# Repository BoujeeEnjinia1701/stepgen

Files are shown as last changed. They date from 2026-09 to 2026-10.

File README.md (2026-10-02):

# StepGen

     

**Area:** Mobility and Logistics · **TRL:** 3 of 9 (proof of concept on paper) · **Value-engineering target:** $650 USD on the salvage reference build (estimated cost of the constructable design $610), SwapCell pack excluded · **Difficulty:** 3 of 5

Walking-treadmill vehicle: the rider stands upright and walks at a normal pace on a short free-running belt between the wheels, a belt-speed sensor sets the assist of a 250 W hub motor, and the vehicle moves at e-bike speed (up to 25 km/h) on a shared SwapCell pack. Walking is the control input; the motor does the work.

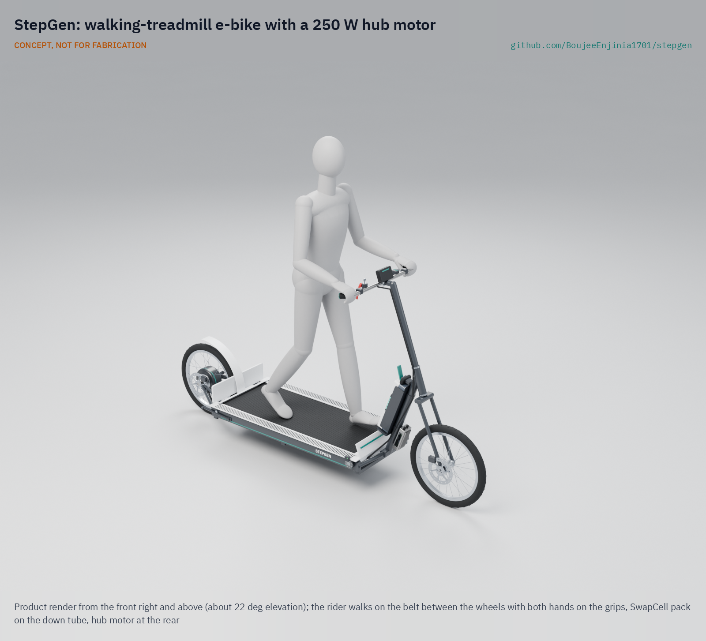
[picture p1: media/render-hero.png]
StepGen: walking-treadmill e-bike with a 250 W hub motor, product render


[Exploded render](media/render-exploded.png) · [Detail render](media/render-detail.png) · [Interactive 3D model](media/viewer.html) · [General arrangement (PDF)](cad/drawings/SGN-DWG-001.pdf) · [Concept blueprint (PDF)](media/concept-blueprint.pdf) · [Sizing note](docs/04-calcs/01-sizing.md) · [Prototype build plan](docs/05-build-plan.md) · [Design decisions](docs/06-design-decisions.md) · [Review note](docs/REVIEW.md)

## Concept rationale

Walking is the one way of moving that almost everyone already knows, so StepGen uses it as the control input instead of asking new riders to learn to pedal and balance on a saddle. The rider walks at an ordinary pace on a free-running belt; a sensor reads that pace and a 250 W hub motor does the propulsion, because a person walking puts only about 30 to 41 W into the belt, far less than the 136 W the vehicle needs at 20 km/h ([SGN-CAL-001](docs/04-calcs/01-sizing.md)). Walking sets the speed, gives light exercise and stops the motor as soon as the rider stops.

Commercial walking bikes exist but cost from about €3,000 and weigh about 55 kg ([Lopifit, "What is a Lopifit?"](https://www.lopifit.com/what-is-a-lopifit/)). StepGen is open hardware so that a local welder or bike mechanic can build it from a salvaged walking-pad treadmill, a donor 20 in bike and common e-bike parts for about $610, share one SwapCell pack with other portfolio vehicles, and adapt the design to the riders they serve.

## Burning platform

The WHO reports that 31 % of adults worldwide did not meet the recommended levels of physical activity in 2022, a share that has risen since 2010 ([WHO, physical activity fact sheet](https://www.who.int/news-room/fact-sheets/detail/physical-activity)). At the same time, populations are ageing: by 2030 one in six people in the world will be aged 60 or over, 1.4 billion people, and by 2050 two-thirds of them will live in low- and middle-income countries ([WHO, ageing and health fact sheet](https://www.who.int/news-room/fact-sheets/detail/ageing-and-health)).

Many of these people make short daily trips that are too long to walk and too costly by car, and e-bikes serve them only if they can already cycle. A vehicle driven by ordinary walking could give non-cyclists and older adults the reach of an e-bike together with daily activity, but only if it is cheap and simple enough to be built and repaired locally.

## Where it could be used

### By industry

| Industry | Use |
| --- | --- |
| Urban mobility and bike share | A pedal-free option in shared fleets for riders who do not cycle |
| Healthy ageing and community services | Errands and clinic visits for older adults who can walk but are nervous on a saddle |
| Workplace and campus mobility | Moving staff across large sites, factories, hospitals and universities at walking effort |
| Tourism and leisure | Rentals on promenades and park paths, where riding a walking bike is itself the attraction |
| Last-mile commuting | The trip between home and a train or bus station for commuters who want light exercise |
| Local fabrication and repair | A product that bike mechanics and welders can build and service from salvaged parts |

### By country or region

| Country or region | Why it matters there |
| --- | --- |
| Netherlands | 27 % of all journeys are made by bicycle and more than half of all car trips are shorter than 7.5 km ([Government of the Netherlands, bicycle policy](https://www.government.nl/topics/bicycles/bicycle-policy-in-the-netherlands)); the Lopifit walking bike was developed here ([Lopifit](https://www.lopifit.com/what-is-a-lopifit/)), so dense cycle infrastructure and a working reference vehicle already exist |
| Japan | 29.1 % of the population was aged 65 or over on 1 October 2023 ([Cabinet Office, Annual Report on the Ageing Society 2024](https://www8.cao.go.jp/kourei/english/annualreport/2024/pdf/2024.pdf)); an upright, walking-paced vehicle suits older adults on short local trips |
| United States | Federal e-bike law assumes operable pedals ([15 USC 2085](https://uscode.house.gov/view.xhtml?req=granuleid%3AUSC-prelim-title15-section2085&num=0&edition=prelim)), so a walking vehicle is a test case for how rules treat pedal-free, low-power assist |
| India | The world's second-largest market for electric two-wheelers, with 2023 sales up 40 % on 2022, and after subsidies an electric two-wheeler cost more than 15 % less than its petrol equivalent ([IEA, Global EV Outlook 2024](https://www.iea.org/reports/global-ev-outlook-2024/trends-in-other-light-duty-electric-vehicles)); buyers already choose light electric vehicles on price, so a low-cost build matters |
| Kenya | One of the countries where UNEP supports electric two- and three-wheeler projects, in a region where motorcycle numbers in many African countries are growing at some of the highest rates in the world ([UNEP, electric two and three wheelers](https://www.unep.org/topics/transport/electric-mobility/electric-two-and-three-wheelers)); a locally built vehicle on a shared SwapCell pack fits that shift, though demand and rules need a desk study |
| Latin America | Two- and three-wheelers play a critical role in daily passenger and commercial transport in Latin America and Africa ([IEA, Global EV Outlook 2024](https://www.iea.org/reports/global-ev-outlook-2024/trends-in-other-light-duty-electric-vehicles)); a light vehicle that local workshops can build and repair could serve the same trips |

## What sparked the idea

The starting point was the electric walking bike that Amish has seen in the Netherlands, of the Lopifit type: the rider walks upright on a treadmill belt between the wheels, and the bike moves forward instead of being pedalled. The Lopifit is a Dutch invention by Bruin Bergmeester, who drove to work, found it hard to keep a healthy weight and decided that should change; the company is based in Utrecht ([Lopifit, "What is a Lopifit?"](https://www.lopifit.com/what-is-a-lopifit/); [Lopifit, "Our story"](https://www.lopifit.com/our-story/)). It shows that a walking vehicle works and can be sold, but its price and mass put it out of reach of many of the people who would gain most from it. StepGen asks whether the same idea can be made light, open and garage-buildable on a shared battery.

## Problem

Many people who would gain from an e-bike never ride one because cycling needs riding skill, balance on pedals and a seated posture that does not suit everyone, while walking is natural and needs none of these. Short trips of 2 to 15 km stay too long to walk and too costly by car. Design with, not for: requirements must come from co-design sessions and field trials with the intended users through a local partner.

## Concept

Walking-treadmill vehicle: the rider stands upright and walks at a normal pace on a short free-running belt between the wheels, a belt-speed sensor sets the assist of a 250 W hub motor, and the vehicle moves at e-bike speed (up to 25 km/h) on a shared SwapCell pack. Walking is the control input; the motor does the work.

Full design precis: [docs/02-concept.md](docs/02-concept.md)

## Key components

- Long-wheelbase welded steel frame (2.38 m long with the fender, 1.86 m wheelbase, 60 x 30 x 2 mm deck rails) with two 20 in wheels
- Free-running treadmill belt on a roller bed, with a one-way bearing in the rear roller so the belt runs rearward only
- Belt-speed sensor that sets the motor assist
- 250 W geared rear hub motor and 48 V controller, assist cut at 25 km/h, 15 km/h beginner mode
- Shared 48 V SwapCell pack (interface v0.3) in a down-tube cradle to latch class V1, woken by a 10 kΩ INTERLOCK coding resistor (pack not in the parts cost)
- Two disc brakes with motor cut-off levers, a lanyard stop switch and a key switch in the SwapCell INTERLOCK loop
- Guards over the belt rollers and the rear tire

TRL 3 sizing ([SGN-CAL-001](docs/04-calcs/01-sizing.md)): about 9.1 Wh/km at 20 km/h, about 45 km per SwapCell pack on the flat, 35.1 kg without the pack, and an estimated $610 in parts excluding the pack on the salvage reference build, $40 under the $650 value-engineering target ($750 with all new parts; see [SGN-DDR-002](docs/decisions/0002-recommendations-accepted.md), [SGN-DDR-003](docs/decisions/0003-design-for-construction.md) and the [review note](docs/REVIEW.md)). The parametric model is `cad/src/model.py`, with STEP files in `cad/step/`.

The priced bill of materials is in [bom/bom.csv](bom/bom.csv).

## Building the prototype

The [prototype build plan](docs/05-build-plan.md) (SGN-BLD-001) shows how to build the first proof-of-concept StepGen, component by component, with a making sketch for every made part, close-ups of the joints and a picture for every assembly step. The frame is welded from stock steel tube and plate; the belt and rollers come from a used walking-pad treadmill and the wheels, brakes and motor are bought. Making the concept buildable changed some parts (rear stays, nose beam, head tube, cradle, guards and fixings) without changing what the vehicle does; the changes are in [SGN-DDR-003](docs/decisions/0003-design-for-construction.md), and decisions still open are in the [design decisions register](docs/06-design-decisions.md). It is a plan: building and testing to it is TRL 4 work.

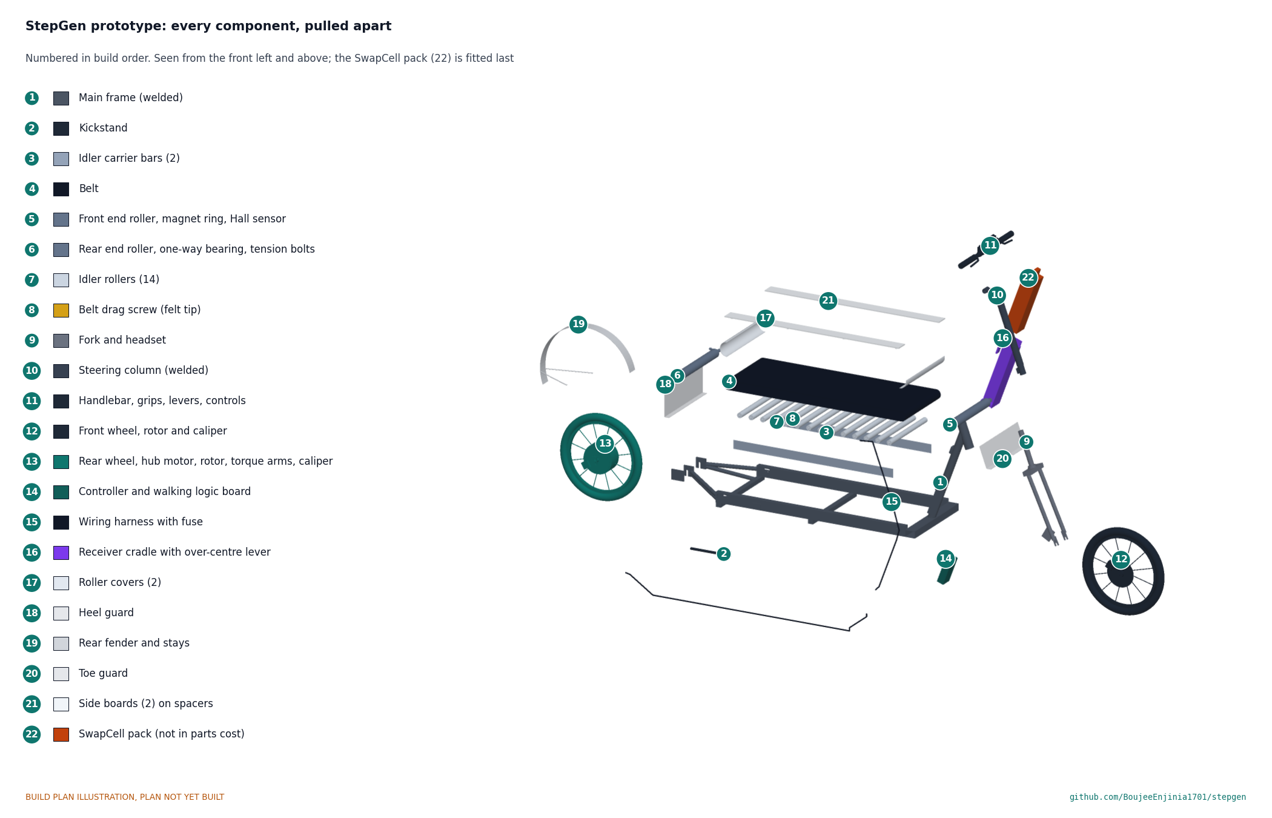
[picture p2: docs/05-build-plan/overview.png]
StepGen prototype: every component, pulled apart and numbered in build order


## Safety

> **Safety:** A rider stands on a moving belt on a moving vehicle. The motor must run only while the rider walks and stop when the belt stops, a brake is pulled or the lanyard comes out. Guard the belt rollers and the rear tire, keep the deck low with open sides, limit speed to 25 km/h, and wear a helmet. The SwapCell pack is a 468 Wh lithium-ion battery held by a class V1 latch; every circuit stays under 60 V DC. This is a paper design at TRL 3; nothing here clears it for building or riding.

## Repository layout

| Folder | Contents |
| --- | --- |
| `docs/` | Problem, concept, requirements, calculations, prototype build plan and design decisions |
| `cad/src/` | build123d Python source, the source of truth for all geometry |
| `cad/step/`, `cad/stl/` | Exported models for FreeCAD, other CAD tools and printing |
| `cad/drawings/` | 2D sketches and dimensioned drawings |
| `bom/` | Bill of materials |
| `electronics/` | KiCad schematics and PCB layouts |
| `firmware/` | Microcontroller code |
| `media/` | Renders, perspectives and photos |
| `build-log/` | Dated prototyping notes |

## Documentation

Controlled documents follow the portfolio [documentation standard](.kit/STANDARDS.md). Each carries a document ID (SGN-PRC-001 for the precis), a version and a revision history. Branded PDFs are built with `python .kit/render.py` and attached to GitHub Releases when a document is tagged, for example `SGN-PRC-001/v1.0`.

## Credits

Designed by Amish Chadha. See [CONTRIBUTORS.md](CONTRIBUTORS.md) for roles. To cite this design, use [CITATION.cff](CITATION.cff) (GitHub shows it as "Cite this repository").

AI assistance (Claude) was used to accelerate concept renders, prototype documentation and first-pass sizing calculations. Design direction and all decisions are Amish Chadha's, recorded in this repository's decision records (`docs/decisions/`).

## Licenses

- **Hardware** (CAD, drawings, BOM, electronics): [CERN-OHL-S v2](LICENSE)
- **Software** (firmware, scripts, notebooks): [MIT](LICENSE-SOFTWARE)

A project of the [Design Molecule](https://designmolecule.com) lab.

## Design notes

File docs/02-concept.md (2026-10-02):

---
doc_id: SGN-PRC-001
title: StepGen design precis
project: StepGen
doc_type: Design precis
version: "0.7"
status: Draft
date: '2026-10-02'
author: Amish Chadha
license: CERN-OHL-S-2.0
revisions:
- version: "0.1"
  date: '2026-09-24'
  author: Amish Chadha
  change: Initial scaffold
- version: "0.2"
  date: '2026-09-24'
  author: Amish Chadha
  change: Populate to TRL 2 (architecture, first-order numbers, efficiency chain, safety, media)
- version: "0.3"
  date: '2026-09-25'
  author: Amish Chadha
  change: Concept changed at Amish's direction from a stationary stepper generator to a walking-treadmill vehicle
- version: "0.4"
  date: '2026-09-25'
  author: Amish Chadha
  change: TRL 3. Record Amish's decisions (SGN-DDR-001); SwapCell interface v0.3 (coded INTERLOCK wake, latch class V1 receiver); fork offset and 38 mm column; numbers checked against SGN-CAL-001; GA drawing SGN-DWG-001
- version: "0.5"
  date: '2026-09-25'
  author: Amish Chadha
  change: Recommendations accepted by Amish (DDR-002)
- version: "0.6"
  date: '2026-10-01'
  author: Amish Chadha
  change: Design made constructable (SGN-DDR-003, draft); numbers from SGN-CAL-001 v0.3; cost against the value-engineering target; build plan SGN-BLD-001 and register SGN-DEC-001 linked
- version: "0.7"
  date: '2026-10-02'
  author: Amish Chadha
  change: 'Decisions of 2026-10-02: first country and RDW check, balance test with the first user group'
---

# StepGen design precis

StepGen is a walking-treadmill vehicle. The rider stands upright on a free-running belt (end rollers 1.05 m apart) between two 20 in wheels and walks at an ordinary 4 to 6 km/h; a sensor on the belt roller reads the walking speed, and a 250 W geared hub motor in the rear wheel, powered by a shared SwapCell pack, drives the vehicle at up to 25 km/h. The belt is a control input, not the engine: walking puts only about 30 to 41 W into the belt at 5 km/h, while cruising at 20 km/h needs about 136 W at the wheel. The sizing note SGN-CAL-001 v0.2 gives about 9.1 Wh/km at 20 km/h, about 45 km on one SwapCell pack on the flat, 35.1 kg without the pack and a parts cost of about USD 610 excluding the pack on the salvage reference build, against a USD 650 value-engineering target (USD 750 with all new parts). The constructable design of SGN-DDR-003 is built step by step in the prototype build plan SGN-BLD-001 (`docs/05-build-plan.md`); open decisions are in the design decisions register SGN-DEC-001 (`docs/06-design-decisions.md`). The general arrangement is drawing SGN-DWG-001 (`cad/drawings/SGN-DWG-001.pdf`), generated from `cad/src/model.py`.

> **Decisions.** Amish decided on 2026-09-24 that StepGen becomes a walking-treadmill vehicle like the Lopifit walking bike: "as the person walks his scooter / bike moves forward but hes upright walking instead of pedalling". The stationary stepper generator of version 0.2 is dropped entirely and no longer charges a PowerBox. On 2026-09-25 Amish accepted the TRL 2 recommendations for form factor, wheels, motor and speed class, range, regeneration, area, budget and legal route, and the move to SwapCell interface v0.3 (SGN-DDR-001). On 2026-09-25 he also accepted the TRL 3 recommendations (SGN-DDR-002): the salvage route as the reference build within $650, the 1.05 m belt kept until co-design, 60 x 30 x 2 mm deck rails and a key switch in the INTERLOCK loop. Items still proposed, awaiting Amish, are marked as such.

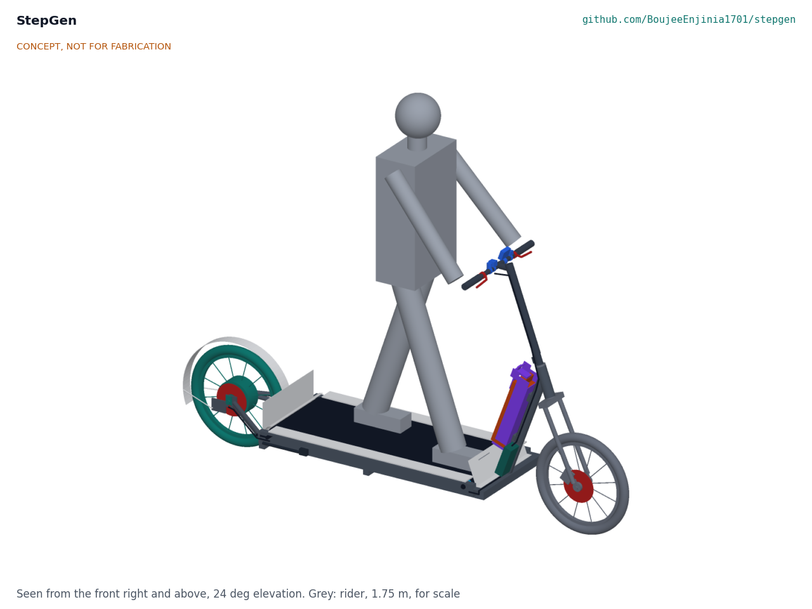
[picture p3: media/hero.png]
Hero render


*Figure 1. StepGen model (`cad/src/model.py`) with a 1.75 m rider standing on the belt mid-stride. Concept, not for fabrication.*

## How it works

1. **Switch on and step on.** The rider turns the key (decided by Amish, 2026-09-25, SGN-DDR-002), which closes the SwapCell INTERLOCK loop through its 10 kΩ coding resistor and wakes the pack (interface v0.3 item W). The rider stands on the belt deck, which is 240 mm (9.4 in) above the ground with open sides, holds the handlebar and clips the lanyard stop to a wrist or belt.
2. **Walk.** The rider walks forward at a normal pace. The belt is not powered: the rider's feet push it rearward over a bed of small rollers, the way a non-motorized treadmill works. An anti-reverse clutch on the rear roller lets the belt run only rearward.
3. **Sense.** A Hall sensor on the front roller reads belt speed, which equals walking speed (one pulse per 19.6 mm of belt). The logic board also reads both brake levers, the lanyard switch and the level selector.
4. **Assist.** When the belt has run above 1.5 km/h for 0.5 s, the logic board commands motor power in proportion to belt speed, scaled by the selected level (three levels) and capped at 250 W and 25 km/h. Walking faster asks for more power; walking slower asks for less.
5. **Drive.** The controller drives a 250 W geared hub motor in the 20 in rear wheel from the SwapCell pack at about 39 to 54.6 V.
6. **Stop.** When the rider stops walking, the motor turns off in about 0.26 s; a brake lever or the lanyard cuts it in about 30 ms. Two disc brakes stop the vehicle. The anti-reverse clutch holds the belt, so the rider's feet brace on it as on a scooter deck instead of sliding forward.
7. **Step off and park.** The rider steps sideways off the low deck, puts the kickstand down and turns the key off; the pack opens its output within 1 ms and sleeps.

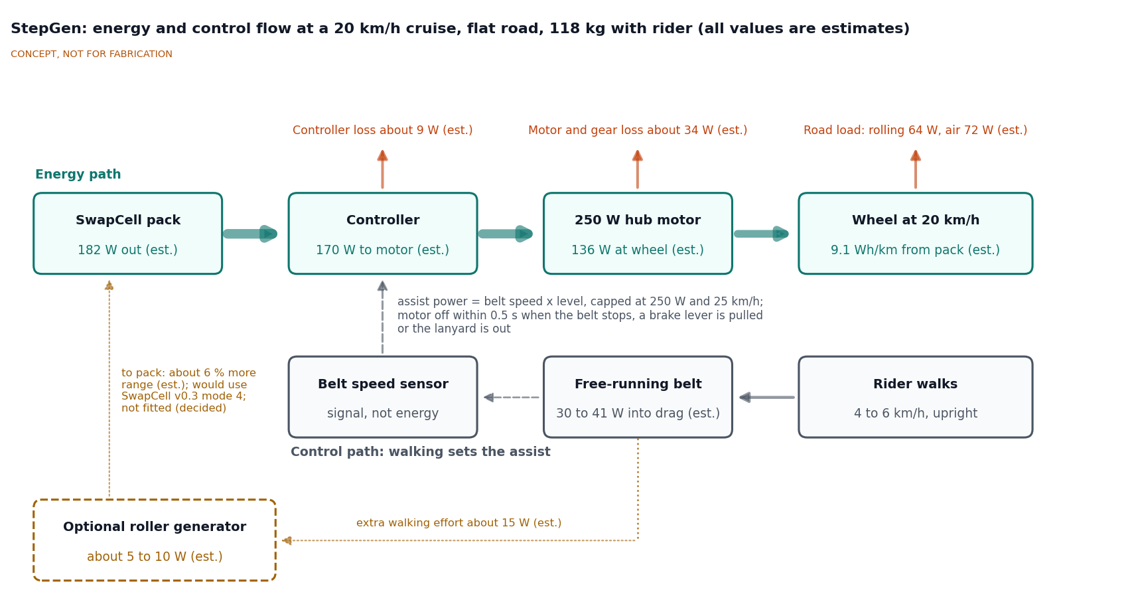
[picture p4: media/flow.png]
Energy flow


*Figure 2. Energy and control flow at a 20 km/h cruise on the flat. The energy path runs from the pack to the wheel; walking is on the control path. The optional roller generator (not fitted) is dashed. All values are estimates from SGN-CAL-001.*

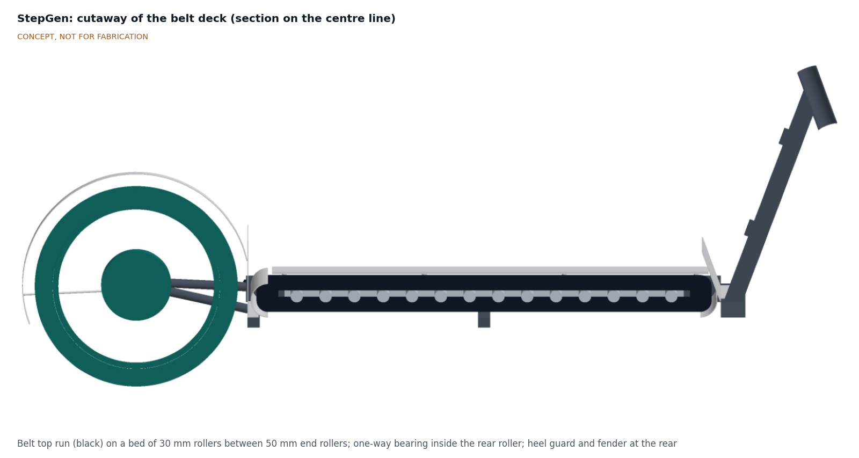
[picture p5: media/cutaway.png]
Cutaway


*Figure 3. Section through the belt deck on the vehicle centre line.*

## Main components

Numbers match the exploded view and `bom/bom.csv`.

| # | Component | Choice | Notes |
| --- | --- | --- | --- |
| 1 | Main frame | Welded mild steel: 60 x 30 x 2 mm deck rails, two cross members under them, a nose beam, four rear stays, 44 mm down tube, bought head tube machined for a ZS44 headset | Wheelbase 1.86 m; about 12.7 kg; rails decided by Amish, 2026-09-25 (SGN-DDR-002) |
| 2 | Belt and end rollers | 400 mm treadmill belt, two 50 mm crowned rollers 1.05 m apart, tensioner at about 500 N per run | Belt top 240 mm above the ground; 1.00 m usable |
| 3 | Roller bed | 14 gravity conveyor rollers, 30 mm, at about 70 mm pitch under the top run | Push about 22 to 30 N; a slider deck would need 78 to 157 N |
| 4 | Anti-reverse clutch and belt drag | One-way (sprag) bearing inside the rear roller; felt-tipped drag screw through the right rail | Belt runs rearward only; drag sets the feel |
| 5 | Belt speed sensor | Hall sensor and 8-magnet ring on the front roller | The only input that commands assist |
| 6 | Rear wheel with 250 W geared hub motor | 48 V 250 W geared hub wound for a 20 in wheel (about 400 rpm no-load at 48 V), torque arms | Decided by Amish, 2026-09-25 |
| 7 | Front wheel, fork and headset | 20 in wheel, steel disc fork with 30 mm offset, 70° head angle | Trail 58 mm |
| 8 | Steering column, handlebar and grips | 38 x 2 mm steel column to a 1.23 m bar height (0.99 m above the belt), 580 mm bar | Sized for a 500 N push at the bar; height adjustable after co-design |
| 9 | Brakes with motor cut-off levers | Two mechanical disc brakes, 160 mm rotors, cut-off switches in both levers | |
| 10 | SwapCell receiver cradle, class V1 | Steel cradle on the down tube with guide faces, end stop, latch catch, floating receptacle, over-centre lever with detent (330 N preload or more) and a 10 kΩ INTERLOCK coding resistor | SwapCell interface v0.3 items V and W |
| 11 | SwapCell pack | 13S2P, about 46.8 V nominal, about 468 Wh, 2.85 kg | Shared; priced once in the SwapCell BOM, not in the StepGen parts cost |
| 12 | Controller and walking logic board | 48 V, 15 A sine-wave controller; ESP32 with CAN, which is also the SwapCell host | Logic is a labeled sketch only |
| 13 | Display, level selector, lanyard stop, key switch | Speed, level and charge display; magnetic lanyard switch; key switch in the INTERLOCK loop | Key switch decided by Amish, 2026-09-25 (SGN-DDR-002) |
| 14 | Guards | Heel guard and fender over the rear tire, roller end covers, side boards, toe guard | See Safety |
| 15 | Wiring harness with fuse | Keyed waterproof connectors, 20 A fuse | |

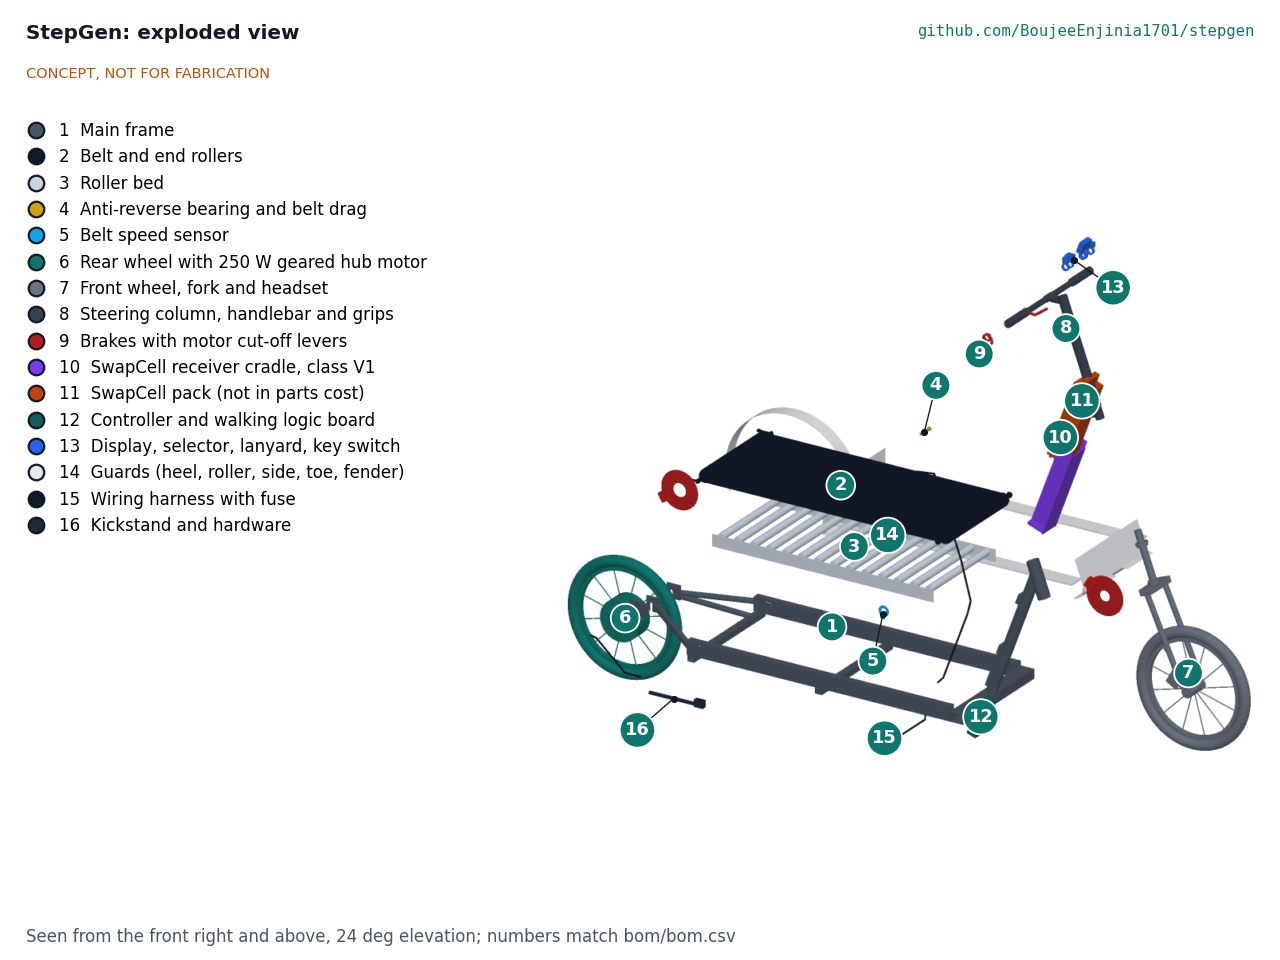
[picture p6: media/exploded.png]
Exploded view


*Figure 4. Exploded view with BOM numbers. Item 16 (hardware and kickstand) has no callout.*

## Key numbers

All values come from the sizing note SGN-CAL-001 (`docs/04-calcs/sizing.py`), which uses the geometry of `cad/src/model.py`. They are paper estimates, not measurements. Main assumptions: rider 80 kg, vehicle 35.0 kg, SwapCell pack 2.85 kg, total 117.9 kg; rolling resistance coefficient 0.010; standing rider drag area CdA 0.70 m²; air density 1.2 kg/m³; motor and gearbox 80 % and controller 95 % efficient; 3 W auxiliary load; usable pack energy 411 Wh (457 Wh at the terminals per cycle, 10 % reserve); roller-bed coefficient 0.02.

*Table 1. Key numbers.*

| Quantity | Value | Basis | Requirement |
| --- | --- | --- | --- |
| Walking speed on the belt | 4 to 6 km/h (2.5 to 3.7 mph) | Normal adult walking pace | R1 |
| Vehicle speed | Up to 25 km/h (15.5 mph); 15 km/h beginner mode; about 20 km/h typical cruise | Assist cut-off set in firmware; road load equals 250 W at 26.4 km/h | R3 met on paper |
| Motor power | 250 W rated; 136 W at the wheel at 20 km/h and 221 W at 25 km/h | Road load: rolling 0.010 x 117.9 kg x 9.81 x v, plus air 0.5 x 1.2 x 0.70 x v³ | R4 met on paper |
| Pack power and current | 182 W and 3.9 A at 20 km/h; 294 W and 6.3 A at 25 km/h; at most 8.5 A at 39 V; 15 A controller limit | Wheel power over 0.80 x 0.95, plus 3 W | R11 met on paper |
| Energy per km | 7.1 Wh/km at 15 km/h, 9.1 Wh/km at 20 km/h, 11.8 Wh/km at 25 km/h | Pack power over speed, flat, steady, no wind | |
| Range on one SwapCell pack | 58 km at 15 km/h, 45 km at 20 km/h, 35 km at 25 km/h on the flat; about 32 km at 20 km/h in real use | 411 Wh usable; real use x 1.4 energy | R5 (30 km at 20 km/h) met |
| Hill | 8 % at 8 km/h needs 235 W at the wheel (26.1 N m); at 250 W the vehicle climbs 5 % at 12.1 km/h and 10 % at 7.0 km/h | Grade plus road load | R6 at risk (6 % margin) |
| Acceleration | Limited to 1.0 m/s² by a 32 N m torque limit; 0 to 20 km/h in about 12 s | 250 W cap | R3 met on paper |
| Mass | 35.1 kg without the pack, 37.9 kg with it | Table 2 of SGN-CAL-001 | R10 at risk (2.1 kg margin) |
| Size | 2.38 m long with the rear fender (2.35 m over the tires), 0.58 m wide at the bar, 1.29 m high; wheelbase 1.86 m | Model | R10 met on length and width |
| Belt | End rollers 1.05 m apart, 1.00 m usable, 400 mm wide, top 240 mm above the ground; 145 mm ground clearance | Model | R1 at risk (belt kept until co-design), R8 met |
| Rider push and power into the belt | 21.7 to 29.7 N at 5 km/h, or 30 to 41 W, all dissipated as belt drag | Roller bed 0.02 x 80 kg x 9.81 = 15.7 N, plus bending, bearings and the 0 to 8 N drag setting | R1 |
| Rider effort | About 250 to 350 W metabolic, light exercise similar to ordinary walking | About 3 to 3.5 MET for an 80 kg adult | |
| Motor off | 261 ms after the belt stops; about 30 ms from a brake lever or the lanyard | Timing budget | R2 met on paper |
| Braking | 8.0 m from 25 km/h at 3 m/s²; rear brake alone 9.6 m, front alone 4.5 m | v² / 2a with load transfer | R7 met on paper |
| Steering | 70° head angle, 30 mm fork offset, 58 mm trail; 32.6° lean clearance | Model | |
| Optional roller generator (not fitted) | 5 to 10 W to the pack in SwapCell mode 4 for about 15 W of extra walking effort; about 5 % more range | Small BLDC at about 60 % from belt to pack | Decided: not in the first concept |
| Parts cost | USD 610 excluding the pack on the salvage reference build; USD 750 with all new parts | `bom/bom.csv` | R12: USD 40 under the USD 650 value-engineering target (reference build) |

### Why the motor does the work

Walking on the belt delivers about 30 to 41 W at 5 km/h, and all of it is spent pushing the belt over its rollers. Even if a mechanical drive delivered 40 W to the wheel with no loss at all, road load would limit the vehicle to 9.8 km/h on flat pavement, and it would stall on a 3 % grade, which needs 65 W at 5 km/h. After drivetrain losses, walking pace is the realistic result. This matches reports from mechanical treadmill-bike builders ([SolidSmack](https://www.solidsmack.com/design/evolution-unusual-treadmill-bicycle/)). The Lopifit also drives its wheel with a 250 W motor, not with the belt ([New Atlas](https://newatlas.com/urban-transport/lopifit-electric-scooter-treadmill-bike-walking/)).

### Assist law (sketch, not firmware)

A labeled sketch of the control rule. It is not firmware, and no firmware is written at TRL 3:

- Assist power P = k(level) x v_belt, with k chosen so that walking at 5 km/h gives about 100, 175 or 250 W at levels 1, 2 and 3. Power is capped at 250 W and tapered to zero between 23 and 25 km/h (15 km/h in beginner mode).
- Drive force is limited to 129 N (32.0 N m at the hub), so acceleration from rest is 1.0 m/s² or less, and the power command ramps at no more than about 100 W/s, so the vehicle cannot surge ahead of the rider. The 250 W cap leaves 0.64 m/s² at 10 km/h and 0.17 m/s² at 20 km/h.
- Assist is off unless the belt has run above 1.5 km/h for 0.5 s (11 sensor pulses). A stop is declared after three missed pulse periods (141 ms), and the motor is off 261 ms after the belt stops. The brake-lever and lanyard switches cut the controller directly, in about 30 ms.

### SwapCell interface

StepGen builds to **SwapCell interface v0.3** unchanged (SWC-PRC-001 v0.3, SWC-DDR-001), as Amish decided on 2026-09-25 (SGN-DDR-001 item 9):

- **Wake, item W.** The receiver cradle fits a 10 kΩ ±1 % coding resistor between INTERLOCK and SGND, which holds the pack's sense node at 0.30 V (accepted window 0.24 to 0.37 V) and wakes a sleeping pack with no supply from the vehicle. The WAKE pin is not used. A key switch sits in series with the resistor (decided by Amish, 2026-09-25, SGN-DDR-002), so that key off opens the loop, the pack cuts its output within 1 ms and sleeps (about 0.72 % of charge per month), and key on wakes it again. The key is for use at a standstill only.
- **Heartbeat.** The ESP32 logic board is the SwapCell host: host type 0 (vehicle), requested mode 2 (discharge), host discharge limit 15.0 A. The CAN bit layout is now defined in v0.3, but the message handling stays a labeled sketch because firmware is beyond TRL 3.
- **Charge-discharge, item C.** Not used. The geared hub freewheels, so there is no regenerative braking, and the roller generator is not fitted (SGN-DDR-001 item 5). If the generator is studied later, it would request mode 4 with a host charge limit of about 0.2 A.
- **Latch class V1, item V.** The cradle on the down tube is a vehicle receiver to class V1: it holds the pack with no release and no power-contact break of 1 ms or longer under 8 g sine vibration and 25 g shocks. An over-centre lever with a detent preloads the pack against its end stop with 330 N or more (ratio 6.6 at a 50 N hand force), and the pack's own latch carries a 1.72 kN proof load. The cradle leaves the pack's back and lid faces open to air, as v0.3 asks, and leaves the flush wake button reachable. Retention can only be shown by test (R13, TRL 4, on hold).
- **Current.** The pack supplies 3.9 A at a 20 km/h cruise and at most 8.5 A, inside the 15 A legacy limit and far from the 20 A case that puts the pack's thermal rating at risk.
- **Flag to the SwapCell project.** The logic board is powered from the pack output, so after a key-on wake the pack enters legacy discharge (no heartbeat within 2 s) before the board can send a heartbeat. The v0.3 behavior rules do not say whether a pack in legacy discharge moves to mode 2 when a heartbeat arrives. StepGen raises this with the SwapCell project and does not change the interface locally (decided by Amish, 2026-09-25, SGN-DDR-002; a cross-repo action).

## Key design choices

Amish decided the change to a walking vehicle on 2026-09-24 and the choices marked "decided" on 2026-09-25 (SGN-DDR-001 and SGN-DDR-002). Choices marked "proposed" await Amish. Unmarked choices (rear drive, roller bed, anti-reverse clutch, pack position) are engineering choices supported by SGN-CAL-001; Amish can revisit any of them.

- **Form factor: two-wheel, long wheelbase, bike type.** Decided. A walking step at 5 km/h is about 0.7 m for a 1.75 m rider, so with the foot the belt needs about 1.0 m of usable length. That sets a long wheelbase (1.86 m). SGN-CAL-001 shows that 1.0 m is short for taller riders or 6 km/h; a longer belt trades against the 2.4 m length limit, and Amish decided on 2026-09-25 (SGN-DDR-002) to keep the 1.05 m roller pitch until co-design shows the riders' heights and pace. Two wheels keep the vehicle narrow for cycle lanes and doors. Alternatives: (a) a compact scooter type with 12 to 16 in wheels and a belt of about 0.7 m, which is shorter and lighter but forces short shuffling steps and copes poorly with rough surfaces; (b) a three-wheel tadpole version with two front wheels, which stands up on its own and suits riders without two-wheel balance, but is wider (about 0.75 m), heavier and less stable in fast turns with a standing rider. Decided by Amish, 2026-09-25: two wheels for the first concept, with the three-wheel version kept open until co-design shows whether non-cyclists can balance.
- **Wheels: 20 in (ETRTO 406) front and rear.** Decided. One tire size, a low deck, common parts. Alternatives: a 28 in front wheel like the Lopifit (rolls better over rough ground, longer vehicle), or 16 in wheels (shorter, harsher ride).
- **Motor and speed class: 250 W rated rear geared hub, assist cut at 25 km/h, 15 km/h beginner mode.** Decided, because it stays within EU pedelec limits and a standing rider has high drag and a high centre of mass. Alternatives: a US class 1 style limit of 20 mph (32 km/h) with a 500 to 750 W motor (more hill ability, more risk for a standing rider, and not legal as a pedelec in the EU), or a lower 20 km/h cap throughout.
- **Rear drive, not front.** The rider's weight sits mostly over the rear half of the deck, which gives the rear wheel traction, and the steering stays light. Alternative: a front hub motor as in SunSpoke (simpler wiring, but a light front wheel can spin on wet surfaces).
- **Roller bed rather than a slider deck.** A slider deck (belt on a waxed board) has a friction coefficient of about 0.1 to 0.2, which would need about 80 to 160 N of push from an 80 kg rider. A roller bed cuts this to about 15 to 30 N.
- **Anti-reverse clutch on the belt.** Lets the rider brace against the belt when braking. Without it, a free belt would let the feet slide forward under deceleration.
- **Pack on the down tube, ahead of the rider's feet.** Keeps the pack clear of the stride and easy to swap from the side. Alternatives: under the deck (too little ground clearance) or on the steering column (heavier steering).
- **Regeneration from the belt: not in the first concept.** Decided. It would return only about 5 to 10 W, costs about $35 to $50 and makes walking harder. SwapCell v0.3 now has the charge-discharge mode it would need, but that does not change the balance. A mounting point on the front roller stays for a later study.
- **Steering geometry: 30 mm fork offset and 38 x 2 mm column (TRL 3).** Without offset the 70° head gave about 90 mm of trail, heavy for a 20 in wheel; 30 mm of offset gives 58 mm. A 32 mm column would reach a factor of only 1.4 on yield under a 500 N push at the bar.
- **Deck rails: 60 x 30 x 2 mm.** Decided by Amish, 2026-09-25 (SGN-DDR-002). The 50 x 25 x 2 mm rails of version 0.4 had ample static strength (factor 2.0), but their walking stress range at the welds (37.6 MPa) was at the fatigue limit (38.8 MPa). The larger rails cut it to 25.5 MPa (static factor 3.0) for 1.08 kg, which leaves a 2.1 kg margin to the 40 kg limit of R10.
- **Cost route: salvage reference build.** Decided by Amish, 2026-09-25 (SGN-DDR-002). A used walking-pad treadmill supplies the belt, rollers and roller bed (items 2 and 3) and a donor 20 in bike supplies the front wheel and brakes (items 7 and 9), for about USD 610 in total; the donor's fork is too short for the head tube, so the fork and headset are bought (SGN-DDR-003). New parts (USD 750) are the fallback.

## Safety

> **Safety:** StepGen is a moving vehicle with a moving belt that a person stands on, driven by a 468 Wh lithium-ion pack at up to 54.6 V DC. Every hazard below needs a design control before any build.

- **Falls on a moving belt.** A rider who trips or stops walking abruptly on a belt can fall. Controls: the belt is free-running, so it stops when the rider stops; the motor turns off within 0.5 s when the belt stops; handlebar at about hip-to-waist height; non-slip belt surface; low deck (240 mm) with open sides so a foot can go down. The dynamics of a rider who stumbles while the vehicle coasts at 20 km/h need a proper study at TRL 3.
- **Dead-man and lanyard cut-off.** A magnetic lanyard clipped to the rider cuts motor power if the rider leaves the deck. Handle sensors like those on the Lopifit ([Lopifit](https://www.lopifit.com/what-is-a-lopifit/)) are an option to study.
- **Braking with feet on a belt.** Under braking the rider's body pushes forward. The anti-reverse clutch stops the belt moving forward, so the feet can brace; the toe guard gives a stop. Braking at about 3 m/s² asks an 80 kg rider to resist about 240 N, which the legs and arms can share. Harder stops risk pitching the rider over the bar, so brake modulation and bar height need checking.
- **Pinch and entanglement.** In-running nips where the belt meets each end roller can trap toes, fingers and clothing, and the rear tire runs close behind the heel. Controls: roller end covers, side boards over the belt edges, a heel guard and fender over the rear tire, and spoke guards. Guard gaps follow ISO 13857 reach distances. Long skirts and laces are a specific risk to check in co-design.
- **Speed.** Assist is cut at 25 km/h and a beginner mode limits it to 15 km/h. Acceleration is limited so the vehicle cannot pull away from the rider.
- **Helmet.** Riders should wear a bicycle helmet. A standing rider's head is about 2 m above the ground, higher than on a bicycle, so a fall is from a greater height.
- **Stability.** A standing rider raises the centre of mass. Tip-over in turns, on cross-slopes and when stepping on or off must be checked at TRL 3, and a kickstand is needed so the vehicle does not fall when parked.
- **Electrical and battery.** Every circuit stays below 60 V DC. The SwapCell pack's BMS, coded interlock and warn-then-derate behavior apply; a sudden loss of power at speed is less dangerous here than a sudden surge, but both are covered by the ramp limit. A 20 A fuse protects the harness. Packs are charged only in a SwapCell dock, never on the vehicle. Turning the key off opens the INTERLOCK loop and cuts the pack output at once, without warn-then-derate, so the key is for use at a standstill only; the lanyard and brake levers cut only the motor.
- **Pack retention.** A pack that leaves its cradle at speed is a 2.85 kg projectile with live contacts. The class V1 receiver, the over-centre lever with its detent and the pack latch must all be in place before riding.
- **Legal use.** Until the legal category is known, StepGen should be used only where the rules allow it.

## Open questions

TRL 3 is the hard stop by Amish's instruction. These questions stay open; the ones that need a test belong to TRL 4, which is on hold.

- Legal category of a pedal-less walking vehicle in the first target country, the Netherlands, to be confirmed with the Dutch vehicle authority (RDW) before any road use (country decided by Amish, 2026-10-02). EU pedelec rules cover pedal-assisted cycles, so the check may set a lower speed cap or require type approval.
- Can non-cyclists balance a two-wheeled walking vehicle, or does the first prototype need three wheels? A fixed co-design test with the first user group, non-cycling adults of working age who walk or take transit, with older adults as the second group once balance is understood (decided by Amish, 2026-10-02): if most cannot ride at walking pace after a short trial, the three-wheel version is designed. Stride length on the belt is checked in the same sessions.
- Belt length for tall riders and brisk walking against the 2.4 m length limit (decided: keep 1.05 m pitch; revisit after co-design).
- Belt drag and walking feel: roller spacing, drag setting and the real roller-bed coefficient (needs a test).
- Rider dynamics when stumbling, stopping walking abruptly or braking hard; bar height and handle position (co-design and test).
- Frame stiffness under a standing load (the deck-rail weld fatigue concern is closed on paper by the 60 x 30 x 2 mm rails).
- Guard gaps against ISO 13857 (R9) and pack retention to class V1 (R13), which need hardware.
- Legacy-to-heartbeat transition in the SwapCell behavior rules (flagged to the SwapCell project; cross-repo action).
- Cost of salvaged parts in the first target region: the $40 and $50 salvage prices are estimates to be checked.

Drawings and media: [general arrangement SGN-DWG-001](../cad/drawings/SGN-DWG-001.pdf), [concept blueprint sheet SGN-DWG-010](../media/concept-blueprint.pdf), [interactive 3D model](../media/viewer.html). Model source: `cad/src/model.py` (STEP files in `cad/step/`).

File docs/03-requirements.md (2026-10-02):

---
doc_id: SGN-REQ-001
title: StepGen requirements
project: StepGen
doc_type: Requirements
version: "0.7"
status: Draft
date: '2026-10-02'
author: Amish Chadha
license: CERN-OHL-S-2.0
revisions:
- version: "0.1"
  date: '2026-09-24'
  author: Amish Chadha
  change: Initial scaffold
- version: "0.2"
  date: '2026-09-24'
  author: Amish Chadha
  change: First measurable requirements for TRL 2
- version: "0.3"
  date: '2026-09-25'
  author: Amish Chadha
  change: Concept changed at Amish's direction from a stationary stepper generator to a walking-treadmill vehicle
- version: "0.4"
  date: '2026-09-25'
  author: Amish Chadha
  change: TRL 3. Record Amish's decisions (SGN-DDR-001); R11 to SwapCell interface v0.3; new R13 (latch class V1); R12 budget $650; status of every requirement from SGN-CAL-001
- version: "0.5"
  date: '2026-09-25'
  author: Amish Chadha
  change: Recommendations accepted by Amish (DDR-002)
- version: "0.6"
  date: '2026-10-01'
  author: Amish Chadha
  change: Status from SGN-CAL-001 v0.3 for the constructable design (SGN-DDR-003); R12 reported against the value-engineering target
- version: "0.7"
  date: '2026-10-02'
  author: Amish Chadha
  change: 'Legal classification note: the Netherlands as first country, category confirmed with the RDW (decided by Amish, 2026-10-02)'
---

# StepGen requirements

These are the requirements for the walking-treadmill vehicle at TRL 3. Amish decided the targets for form factor, wheels, speed class, range and budget on 2026-09-25 (SGN-DDR-001), and accepted the TRL 3 recommendations on cost route, belt length, deck rails and key switch the same day (SGN-DDR-002); the rest remain engineering targets to be revised after co-design with users. Every requirement has been checked by calculation in SGN-CAL-001, and Table 1 gives its status. The stepper generator requirements of version 0.2 are withdrawn with that concept.

*Table 1. Requirements and status (SGN-CAL-001).*

| ID | Requirement | Target | Verification | Status at TRL 3 |
| --- | --- | --- | --- | --- |
| R1 | Natural walking on the belt | Usable belt length 1.0 m or more between roller tangents and belt width 0.36 m or more; horizontal force to walk the belt 30 N or less at 5 km/h for an 80 kg rider | Deck geometry in the model; belt drag calculation | At risk: 1.00 m and 22 to 30 N meet the target, but 1.00 m fits a 1.75 m rider only up to 5 km/h; belt kept until co-design (SGN-DDR-002) |
| R2 | Motor runs only while the rider walks | Assist starts only when belt speed stays above 1.5 km/h for 0.5 s; assist power rises with belt speed; motor off within 0.5 s of the belt stopping, either brake lever being pulled or the lanyard coming out | Control logic review; timing budget | Met on paper: 261 ms from belt stop, about 30 ms from a brake lever or the lanyard |
| R3 | Speed limit | Assist cut off at 25 km/h or less, set in firmware; a beginner mode capped at 15 km/h; acceleration limited to 1.0 m/s² or less (decided by Amish, 2026-09-25) | Controller configuration; dynamics calculation | Met on paper: 32 N m torque limit |
| R4 | Motor power in the pedelec class | Rated continuous motor power 250 W or less (decided by Amish, 2026-09-25) | Motor datasheet | Met on paper |
| R5 | Range on one shared pack | 30 km or more at a steady 20 km/h on flat pavement with an 80 kg rider, using the usable energy of one SwapCell pack (decided by Amish, 2026-09-25) | Road-load and energy calculation | Met: 45 km |
| R6 | Hill capability | Climb an 8 % grade at 8 km/h or more with an 80 kg rider, within the motor's rating | Road-load calculation | At risk: 235 W against 250 W |
| R7 | Braking | Two independent hand brakes; stop from 25 km/h within 10 m of brake application on dry pavement, at a deceleration a standing rider can hold (about 3 m/s²); the belt cannot run forward under the rider's feet when braking | Brake calculation; clutch specification | Met on paper: 8.0 m; 9.6 m on the rear brake alone |
| R8 | Rider can step off and put a foot down | Belt top 250 mm or less above the ground; open sides with no rail higher than the deck along the belt | Massing model | Met: 240 mm |
| R9 | Guard pinch and entanglement points | Belt in-running nips at both rollers, wheel spokes and the rear tire all covered or out of reach of feet, toes and fingers; heel guard between the belt's rear end and the rear tire | Design review against ISO 13857 reach distances | Not verifiable at TRL 3 |
| R10 | Size and mass | Length 2.4 m or less, width 0.65 m or less at the handlebar, mass 40 kg or less with the pack | Model; mass estimate | At risk: 2.38 m (with the fender) and 0.58 m met; 37.9 kg leaves 2.1 kg |
| R11 | Shared SwapCell pack | Uses the SwapCell interface v0.3 unchanged: 10 kΩ coding resistor in the INTERLOCK loop (wake, item W), CAN host heartbeat as a vehicle requesting discharge, receiver cradle to the v0.3 envelope; continuous current 15 A or less; every circuit below 60 V DC | Interface review with the SwapCell project | Met on paper: 8.5 A maximum |
| R12 | Low cost and buildable | Parts cost $650 or less excluding the SwapCell pack on the reference build, which uses a salvaged walking-pad treadmill (items 2 and 3) and a donor 20 in bike (items 7 and 9); new parts are the fallback and are reported but not held to this figure (decided by Amish, 2026-09-25, SGN-DDR-001 and SGN-DDR-002; the pack is priced once in the SwapCell BOM); built with hand tools, a drill press and basic welding | Priced BOM | Under the value-engineering target on paper: USD 610, USD 40 under (all new USD 750, USD 100 over) |
| R13 | Pack retention in the vehicle | Receiver cradle meets SwapCell latch class V1 (interface v0.3 item V): no latch release and no power-contact break of 1 ms or longer under 8 g sine and 25 g shocks; pack latch proof 1.72 kN; receiver preload 330 N or more through an over-centre lever with a detent | Paper sizing now; test at TRL 4 (on hold) | Not verifiable at TRL 3 |

> **Safety:** R2, R3, R7, R8, R9 and R13 are safety requirements for a person standing on a moving belt on a vehicle with a 468 Wh lithium-ion pack. Meeting them on paper does not make the vehicle safe to build or ride; they need test evidence at TRL 4, which is on hold.

## Assumptions

- Rider 80 kg and 1.75 m; vehicle 35.1 kg without the pack; SwapCell pack 2.85 kg; total 117.9 kg.
- Rolling resistance coefficient 0.010 for 20 x 1.75 in tires on pavement; standing rider drag area CdA about 0.70 m²; air density 1.2 kg/m³.
- Motor and gearbox efficiency 80 %, controller efficiency 95 %, 3 W of auxiliary load.
- Usable pack energy 411 Wh: the SwapCell sizing note gives 457 Wh at the terminals per full cycle, and a 10 % reserve is kept.
- Walking speed on the belt 4 to 6 km/h; belt rolling-bed coefficient about 0.02.
- The full list is in SGN-CAL-001, Table 1.

## Requirements not met or at risk

- **R1 is at risk.** The 1.0 m target is met exactly, but a 1.75 m rider at 6 km/h, or a 1.90 m rider at 5 km/h, needs more belt. A longer belt breaks the 2.4 m length of R10. Decided by Amish, 2026-09-25 (SGN-DDR-002): keep the 1.05 m roller pitch and revisit after co-design.
- **R6 is at risk.** The 8 % climb needs 235 W at the wheel, a 6 % margin to the 250 W rating.
- **R10 is at risk on mass.** 37.9 kg with the pack leaves 2.1 kg, less than a 10 % growth allowance. The 60 x 30 x 2 mm deck rails (SGN-DDR-002) added 1.08 kg to close the weld fatigue concern.
- **R12 depends on salvage.** `budget_usd` is a hypothetical value-engineering target, not a limit (Amish, 2026-10-01). Value-engineering target: USD 650. Estimated cost of the constructable design: USD 610 on the salvage reference build (USD 40 under the target); the USD 40 and USD 50 salvage prices are estimates, and an all-new build (USD 750) would be USD 100 over the target.
- **R9 and R13** can only be verified on hardware, which is TRL 4 work and on hold by Amish's instruction.
- **Legal classification is unresolved.** R3 and R4 follow EU pedelec limits, but a vehicle without pedals may not qualify as a pedelec in the EU or as an e-bike in the US (see SGN-PRB-001). Amish decided on 2026-09-25 that the category is confirmed in a first target country before any road use, and on 2026-10-02 that the country is the Netherlands, with the category confirmed with the Dutch vehicle authority (RDW). The check may set a lower speed cap than R3 or require type approval.

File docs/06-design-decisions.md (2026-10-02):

---
doc_id: SGN-DEC-001
title: StepGen design decisions register
project: StepGen
doc_type: Design decisions register
version: "0.2"
status: Draft
date: '2026-10-02'
author: Amish Chadha
license: CERN-OHL-S-2.0
revisions:
  - version: "0.1"
    date: '2026-10-01'
    author: Amish Chadha
    change: Register opened; open decisions gathered from the review note, the decision records and the build plan work
  - version: "0.2"
    date: '2026-10-02'
    author: Amish Chadha
    change: 'Amish approved the recommendations for all seven open decisions (2026-10-02); SGN-DDR-003 accepted; moved to decisions made'
---

# StepGen design decisions register

Every design decision still to be made, and every decision made, in one place. Each decision is argued in full in its decision record under `docs/decisions/`; this register is the index Amish works from. The build plan (`docs/05-build-plan.md`) describes the design as it stands and does not list open decisions.

## Open decisions

None. All open decisions were decided on 2026-10-02.

## To confirm when parts are bought

| # | What to confirm | Why it matters | Source |
| --- | --- | --- | --- |
| 1 | The fork: 1 1/8 in threadless rigid steel, 26 in size (axle to crown about 410 mm), 30 mm offset, post-mount disc tabs, steerer 220 mm or longer. If only 38 to 45 mm offsets are found, trail falls from 58 mm to about 42 to 49 mm | Sets trail and steering feel; a 20 in fork is too short for the head tube | SGN-DDR-003 P4 |
| 2 | The head tube is machined for a ZS44 headset and the headset's crown race fits the fork | The headset must fit both | SGN-DDR-003 P4 |
| 3 | The walking-pad treadmill: belt 400 mm or wider, end rollers about 50 mm and 420 mm long, bearings 6203 size on fixed axles that can be drilled and tapped | The one-way bearing (CSK17) and the axle fixings assume these | SGN-DDR-003 P8 |
| 4 | The idler rollers' spring axles: 8 mm round or hex | Sets the carrier bar hole size | SGN-DDR-003 P10 |
| 5 | The hub motor: 135 mm axle width, axle flats that take the torque arms, 6-bolt rotor mount | Sets the dropout spacing and the rear brake | SGN-DDR-003 P2, P3 |
| 6 | The controller fits a 150 x 70 x 40 mm space and has a brake-cut input that both levers and the lanyard can open | Sets the controller plate and the cut-off wiring | SGN-DDR-003 P14 |
| 7 | The SwapCell pack's guide faces and handle end match the cradle (interface v0.3 envelope) | Sets the cradle's inside width and the lever pad | SGN-DDR-003 P13 |
| 8 | The second-hand prices: about USD 40 for a walking-pad treadmill and USD 50 for a donor 20 in bike | The reference build cost depends on them | SGN-DDR-002 item 1 |

## Value engineering

Value-engineering target: USD 650 (a hypothetical control target, not a limit). Estimated cost of the constructable design: USD 610 on the salvage reference build, pack excluded (USD 40 under the target); USD 750 with all new parts (USD 100 over the target). Main cost drivers and savings worth trying:

- The largest lines are the rear wheel with its hub motor (USD 110), the belt and end rollers (USD 97 new, from about USD 40 salvaged with the idlers), the main frame (USD 92, of which USD 25 is the machined head tube), the front wheel, fork and headset (USD 70), and the receiver cradle (USD 55, of which USD 30 is the receptacle).
- Making the design constructable raised the reference build from USD 546 to USD 610: about USD 40 because the donor bike's fork is too short for the head tube, and the rest for the nose beam, head tube, carrier bars, guards, fender, rivet nuts and fixings.
- Savings worth trying: a donor bike with a 26 in fork as well as a 20 in front wheel would save the USD 40 fork; a donor walking pad whose rollers already take a one-way bearing saves the bearing; buying the receptacle with the SwapCell project's batch may halve its price.

## Decisions made

| Date | Decision | Decided by | Record |
| --- | --- | --- | --- |
| 2026-09-24 | StepGen becomes a walking-treadmill vehicle; the stationary stepper generator is dropped | Amish: "as the person walks his scooter / bike moves forward but hes upright walking instead of pedalling" | SGN-PRB-001, SGN-PRC-001 |
| 2026-09-25 | TRL 2 review items: two-wheel long-wheelbase form, 20 in wheels, 250 W rear hub with a 25 km/h cut and 15 km/h beginner mode, 30 km range target, no roller generator, Mobility and Logistics area, USD 650 budget (pack excluded), legal route, SwapCell interface v0.3, shared-pack pricing, co-design partners later | Amish: "proceed with all of your recommendations across all batches. Make sure we don't proceed to TRL 4 on any of them." | SGN-DDR-001 |
| 2026-09-25 | Salvage route as the reference build within USD 650; belt kept at 1.05 m until co-design; 60 x 30 x 2 mm deck rails; key switch in the INTERLOCK loop; raise the legacy-to-heartbeat question with SwapCell | Amish: "i accept all your recommendations, go with them across all repos." | SGN-DDR-002 |
| 2026-09-30 | Make the design physically buildable while drawing the build plan; keep outstanding decisions out of the build plan, in this register | Amish: "If you are realising that the design cannot be built as per concept - fix the design assumptions to match and be physically feasible as you draw the illustrations." | SGN-DDR-003 (accepted on 2026-10-02, below) |
| 2026-10-01 | `budget_usd` is a value-engineering target, not a limit | Amish: "the budgets are a hypothethical control target to ensure we are thinking along a value engineering lens" | This register, Value engineering |
| 2026-10-02 | Design for construction accepted: P1 to P17 and their knock-on changes, as made | Amish: "i approve your recommendations for all 555 open decisions." | SGN-DDR-003 |
| 2026-10-02 | First user group: non-cycling adults of working age who walk or take transit, with older adults as the second group once balance is understood | Amish: "i approve your recommendations for all 555 open decisions." | SGN-DDR-001 item 13, SGN-DDR-002 item 6 |
| 2026-10-02 | First target country for the legal category: the Netherlands, confirming the category with the Dutch vehicle authority (RDW) before any road use; the first country to approach, not a confirmed category | Amish: "i approve your recommendations for all 555 open decisions." | SGN-DDR-001 items 8 and 14, SGN-DDR-002 item 7 |
| 2026-10-02 | Rider pose: the shorter stride is accepted for the renders, and stride length on the 1.0 m belt is added to the co-design checks | Amish: "i approve your recommendations for all 555 open decisions." | `docs/REVIEW.md`, 2026-09-26, item 1 |
| 2026-10-02 | Wheel detail: 28 laced spokes and rotor carriers accepted as appearance only; the rotor carriers are confirmed when the wheel build is specified | Amish: "i approve your recommendations for all 555 open decisions." | `docs/REVIEW.md`, 2026-09-26, item 3 |
| 2026-10-02 | Branding: the wordmark, pinstripe and accent colours are the reference scheme; the "250 W 25 km/h" rating decal is dropped from the renders until the legal category is confirmed | Amish: "i approve your recommendations for all 555 open decisions." | `docs/REVIEW.md`, 2026-09-26, item 4 |
| 2026-10-02 | Three-wheel version: keep two wheels for now and make balance a fixed co-design test: if most non-cyclists cannot ride at walking pace after a short trial, the three-wheel version is designed | Amish: "i approve your recommendations for all 555 open decisions." | SGN-DDR-001 item 1 |

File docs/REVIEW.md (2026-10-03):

# Review note: StepGen

## Session 2026-10-02: open decisions decided by Amish

Authority: Amish, 2026-10-02: "i approve your recommendations for all 555 open decisions." The recommendations approved are those written for the open decisions in the design decisions register. No model, BOM quantity or price, or picture was changed; where a decision needs one, it is listed below as a follow-up. `trl` and `trl_target` stay at 3. No commit or push.

### Decisions recorded

7, all moved to "Decisions made" in `docs/06-design-decisions.md`, dated 2026-10-02:

1. Design for construction (SGN-DDR-003) accepted: P1 to P17 as made.
2. First user group: non-cycling adults of working age who walk or take transit; older adults second, once balance is understood.
3. First target country: the Netherlands, with the legal category confirmed with the RDW before any road use.
4. Rider pose: shorter stride accepted for the renders; stride length on the 1.0 m belt added to the co-design checks.
5. Wheel detail: appearance only; rotor carriers confirmed when the wheel build is specified.
6. Branding: wordmark, pinstripe and accent colours as the reference scheme; the "250 W 25 km/h" rating decal dropped from the renders until the legal category is confirmed.
7. Three-wheel version: keep two wheels; balance becomes a fixed co-design test, and the three-wheel version is designed if most non-cyclists cannot ride at walking pace after a short trial.

### Documents changed

- `docs/06-design-decisions.md` (SGN-DEC-001 v0.2)
- `docs/decisions/0003-design-for-construction.md` (SGN-DDR-003 v0.2): accepted; status stays Draft
- `docs/decisions/0001-trl2-review-decisions.md` (SGN-DDR-001 v0.3): items 13 and 14 decided; balance test noted on item 1
- `docs/decisions/0002-recommendations-accepted.md` (SGN-DDR-002 v0.2): items 6 and 7 decided
- `docs/01-problem.md` (SGN-PRB-001 v0.6): user group, country, balance test, stride check
- `docs/02-concept.md` (SGN-PRC-001 v0.7): country and RDW check; balance test
- `docs/03-requirements.md` (SGN-REQ-001 v0.7): legal classification note
- `docs/05-build-plan.md` (SGN-BLD-001 v0.2): safety stop S7 names the RDW check

### Follow-up actions to carry approved decisions into the design

1. Decision 5 (bom): Confirm the rotor carriers against the hub and front hub when the wheel build is specified (BOM lines for the wheels).
2. Decision 6 (pictures): Remove the "250 W 25 km/h" rating decal from `cad/src/product_model.py` and re-render the photoreal renders, card and social preview on Amish's Mac.
3. Decision 3 (calcs): Once the RDW check is done, restate R3 and R4 in SGN-REQ-001 and SGN-CAL-001 if it sets a lower speed cap or requires type approval.

### Points found in the review

- The 250 W, 25 km/h limits follow EU pedelec rules, which cover only pedal-assisted cycles; a pedal-less vehicle probably falls outside them, so the legal check in item 3 may force a lower speed cap or type approval.

## Session 2026-10-01: design made constructable and prototype build plan (kit 1.7.0)

Under Amish's 2026-09-30 approval of the build plan format ("Extend this across all the other repos") and his instruction to make each design physically buildable while drawing it, this session brought StepGen to the approved standard. TRL stays at 3; nothing was built or tested.

### What was done

- Kit 1.7.0 installed (`.kit/`, `.claude/commands/`, root `CLAUDE.md`).
- `cad/src/model.py` rebuilt from 29 components, each made or bought and fixed to its neighbours, with 72 build123d constructability checks (`python cad/src/model.py --check`): all pass. STEP and STL re-exported.
- `docs/decisions/0003-design-for-construction.md` (SGN-DDR-003, draft): every change and its reason.
- `docs/05-build-plan.md` (SGN-BLD-001 v0.1) from the kit template, with pictures for every component, joint and step.
- `docs/06-design-decisions.md` (SGN-DEC-001 v0.1): open decisions, items to confirm when parts are bought, value engineering, decisions made.
- `cad/src/build_plan_media.py`: overview, 14 making sketches (SGN-DWG-101 to 114), 12 joint close-ups, 19 step pictures (step 6 has two close-ups), a rail hole layout and a wiring diagram. Every picture was looked at and these fixed: the harness is drawn as one cable (its run inside the left rail included) in the overview and step 13; the Hall sensor and rear caliper, too small to show under a number badge, are drawn with the front roller and rear wheel in the overview (22 numbered components); the part being fitted in each step is always in colour; steps 6 and 12 are close-ups; joints 3, 5 and 8 recoloured and re-angled so each part reads; the roller cover sketch draws the two covers side by side so their profiles read. `python .kit/drawing.py --check-text` finds no overlaps.
- `cad/src/sheets.py`: general arrangement SGN-DWG-001 to Rev P3. `cad/src/concept_media.py`: concept media regenerated.
- `docs/04-calcs/sizing.py` and SGN-CAL-001 v0.3 re-run; SGN-PRC-001 and SGN-REQ-001 to v0.6; `bom/bom.csv` and `bom/bom-notes.md` restated and repriced; `project.yaml` (`design_state: constructable`, new evidence); README links line and "Building the prototype" section.

### Design changes made for construction (SGN-DDR-003)

1. Upper rear stays no longer pass through the rear roller and belt: two stays a side, from the rail end caps and the rear cross member to the dropouts.
2. Brake rotors moved inside the dropouts and fork legs; rear caliper on a tab on the left dropout, front caliper on the fork's post mount.
3. Dropouts as 6 mm plates 135 mm apart with slots open downward; torque arms added.
4. Bought head tube machined for a ZS44 headset (50 x 3 mm) replaces the 44 x 3 mm tube; 26 in size fork (axle to crown about 410 mm) carries the 20 in wheel; headset modelled. Steering geometry unchanged.
5. Down tube joins the head tube's side 100 mm above its bottom, so the fork turns 45 degrees each way clear of the frame.
6. Nose tubes and block replaced by a 60 x 40 x 2 mm nose beam across the rail ends.
7. Two cross members welded under the rails (were cut into them); ground clearance 145 mm (was 148 mm).
8. End rollers on fixed axles bolted to the rails; rear axle in slots with M8 tension bolts; anti-reverse clutch is a one-way bearing inside the rear roller; belt drag is a felt-tipped screw through the right rail; magnet ring on the front roller end with the sensor inside the left rail. Lean clearance 32.6 degrees (was 30).
9. Roller centres 3 mm lower so the belt wraps them (it overlapped); belt top still 240 mm.
10. Idler carriers are 50 x 3 mm aluminium bars screwed inside the rails.
11. Side boards on 13 mm spacers, 9 mm proud of the belt (was 6 mm and floating).
12. Heel guard, roller covers and toe guard given flanges and tabs to the frame; bought fender riveted to the heel guard and stayed to the dropouts; front cover now covers the in-running nip under the front roller.
13. Receiver cradle is a folded 3 mm channel on two welded tabs with an end stop plate and an over-centre lever beside the pack handle; pack 0.54 of the way up the down tube (was 0.55).
14. Controller moved from under the down tube (in the front tire's path) to a plate on its left side.
15. Welded steering column that clamps the steerer; straight 580 mm bar (width 0.58 m, was 0.61 m); controls each on their own clamp; display faces the rider.
16. Kickstand on a welded plate; harness inside the left rail between grommets.
17. Overall length 2.38 m with the fender (2.35 m over the tires).

### Key results (SGN-CAL-001 v0.3)

- Vehicle 35.1 kg without the pack, 37.9 kg with it (R10 margin 2.1 kg, at risk as before); 2.38 m long, 0.58 m wide.
- Value-engineering target: USD 650. Estimated cost of the constructable design: USD 610 on the salvage reference build (USD 40 under the target; was USD 546). The donor bike's fork no longer fits the head tube, so the fork and headset are bought (about USD 40). All new: USD 750 (USD 100 over the target).
- Requirement status unchanged: none not met; R1, R6, R10 at risk; R9 and R13 not verifiable at TRL 3; the rest met on paper.

### Decisions proposed and awaiting Amish

Listed in `docs/06-design-decisions.md`: acceptance of SGN-DDR-003 (P1 to P17), first user group, first target country, three render appearance items, and the three-wheel version (open until co-design). Eight items to confirm when parts are bought, including the 26 in fork with 30 mm offset.

### Stale on Amish's Mac

The design changed visibly, so `media/render-hero.png`, `media/render-exploded.png`, `media/render-detail.png`, `media/card.png`, `media/social-preview.png` and the appearance model `cad/src/product_model.py` are stale (they show the nose tubes, swept grips, outboard clutch housing and solid cradle). They were not regenerated here.

### Safety

Unchanged in substance. The build plan adds safety stops for welding, first standing on the belt, the pack and first power (SGN-BLD-001 section 6). The key switch still cuts the pack at once and is for use at a standstill only.

### Recommended next step

Amish reviews SGN-DDR-003 and the register. TRL 4 (building and testing to the plan) stays on hold under the portfolio cap.

## Session 2026-09-26: product appearance model and photoreal renders

Amish chose this repo for the first batch of product renders on 2026-09-26. This session adds an appearance model for photoreal renders; the render images themselves (`media/render-hero.png`, `media/render-exploded.png` and a detail view) are produced later by the portfolio render run.

### What was done

- `cad/src/product_model.py`: `product_parts()` returns 96 parts (67 shell, 21 internal, 7 accessory, 1 context), each with a colour, a material class, its BOM line and an explode offset, plus `TITLE` and three `RENDER_VIEWS` (hero with the rider, exploded, and a detail view without the rider). Geometry reuses `PARAMS` and `geometry()` from `cad/src/model.py`; every main dimension and interface is unchanged.
- Appearance detail added:
  - Painted steel frame with rounded rectangular deck rails, a teal pinstripe, a "STEPGEN" wordmark and a "250 W 25 km/h" decal on the rail sides; headset cups; the kickstand stowed as in model.py.
  - Belt with a fine tread texture; crowned end rollers with axle nuts; the 14 idler rollers on their aluminium angle carriers.
  - Light grey guards (rear fender, heel guard with a rear reflector, roller covers, toe guard with a teal accent) and side boards with ribbed rubber foot pads and screws.
  - 20 in wheels with treaded tires, rims, 28 laced spokes, valves and drilled 160 mm rotors on spider carriers; calipers.
  - Hub motor with a painted shell, aluminium side covers, a bolt circle, a teal band, axle nuts, torque arms and its cable.
  - Anti-reverse clutch housing with a teal drag knob; belt-speed sensor with a clear cap over the 8-magnet ring and a lit pulse light.
  - Controller in a finned case with a clear side window over the walking logic board, ESP32 module and a lit status light; cable glands; the wiring harness with a sealed 20 A fuse holder and cable ties.
  - SwapCell pack (interface v0.3) in the SwapCell visual language: grey tray, light lid, lit charge bar, interface label and ribbed carry handle; class V1 cradle with the teal over-centre lever, pivot and tube clamps.
  - Handlebar with ribbed grips and teal bar-end plugs, brake levers with cut-off switch bodies, display with a lit readout, level selector with a lit ready light, key switch and a red magnetic lanyard stop with a coiled cord.
- Context: the shared clay mannequin (`.kit/context_parts.py`, 1.75 m) standing on the belt with its pelvis over `rider_x` (950 mm), in a walking stride, with both hands on the grips (arm angles solved to the grip points).
- `README.md`: hero image now points to `media/render-hero.png`, with an "Exploded render" link added to the links line.
- Previews (matplotlib, clear parts left out) were checked for the hero, exploded and detail views.

### Where the appearance model differs from model.py

Each item is **Proposed, awaiting Amish**.

1. **Rider pose.** The mannequin uses the "push" preset (hands closed on the grips) with walk-type leg angles and a shorter stride than the kit's walk preset: the preset stride put the leading toe on the toe guard, since the usable belt is 1.0 m. Recommendation: accept for renders; the rider's stride on a 1.0 m belt is worth checking in co-design, because a long stride may reach the toe guard.
2. **Display tilt.** model.py tilts the display top 20 degrees toward the rider, so the screen face on the rider side points slightly downward, away from the rider's eyes. The appearance model keeps the model.py envelope and tilt. Recommendation: reverse the tilt in model.py at the next model update so the screen faces up toward the rider.
3. **Wheel detail.** model.py draws 12 radial placeholder spokes; the appearance model shows 28 laced spokes, a tread and a spider carrier for each rotor (the rotors sit outboard of the hub in model.py). Recommendation: accept as appearance only; confirm the rotor carrier arrangement when the wheel build is specified.
4. **Branding and markings.** The wordmark, rating decal, pinstripe and accent colours are appearance choices, not part of the BOM. Recommendation: accept, or give a preferred marking scheme.

### TRL status

This is an appearance model only, for renders: no tolerances, fabrication detail, PCB layout or build steps. `trl` stays 3 and TRL 4 remains on hold under the portfolio cap.

## Session 2026-09-26: sources strengthened

Amish asked on 2026-09-26 to fix the weaker sources in the README. Every link below was fetched and checked against the claim. No controlled document changed; TRL stays at 3.

| README location | Old source | New source |
| --- | --- | --- |
| Concept rationale (Lopifit price and mass) | Lopifit, "What is a Lopifit?" | Kept (manufacturer's own page; states from €2,999 and 55 kg gross) |
| Countries: Netherlands | Scouters.nl (retailer guidance on 6 km/h pavement rule) | Government of the Netherlands, bicycle policy (27 % of journeys by bicycle; over half of car trips under 7.5 km) and Lopifit; the pavement-rule claim was dropped from the README |
| Countries: India | None | IEA, Global EV Outlook 2024 (second-largest electric two-wheeler market, sales up 40 % in 2023, over 15 % cheaper than petrol after subsidies) |
| Countries: East Africa (for example Kenya) | None | Row narrowed to Kenya; UNEP electric two and three wheelers programme page |
| Countries: Latin America (for example Brazil) | None | Row rewritten as Latin America; IEA, Global EV Outlook 2024 (role of two- and three-wheelers in daily transport). An IBGE census source for Brazil could not be fetched, so Brazil-specific claims were removed |
| What sparked the idea | Lopifit, "What is a Lopifit?" | Strengthened: same page plus Lopifit, "Our story"; wording now matches the source (Dutch invention by Bruin Bergmeester; company based in Utrecht) |

Open: `docs/01-problem.md` still cites Scouters.nl for the Dutch 6 km/h pavement rule and Wikipedia, Redtail, New Atlas and SolidSmack elsewhere. No primary source for the Dutch rule was verified this session; replacing these is left for the next problem-statement revision.

## Session 2026-09-25: recommendations accepted

On 2026-09-25 Amish wrote: "i accept all your recommendations, go with them across all repos." Every open item with a recommendation is now **Decided by Amish, 2026-09-25: go with recommendation**, recorded in `docs/decisions/0002-recommendations-accepted.md` (SGN-DDR-002 v0.1). TRL stays at 3 (`trl: 3`, `trl_target: 3`).

### Decisions applied and what changed

| # | Decision | Before | After |
| --- | --- | --- | --- |
| 1 | Cost (R12): keep $650, salvage route is the reference build, new parts the fallback | R12 not met, $713 all new | R12 met on paper, $546 reference build; $721 all new (reported, not held to R12). `budget_usd` unchanged at $650; R12 text restated |
| 2 | Belt length: keep 1.05 m pitch and 2.35 m length until co-design | R1 at risk | No geometry change; R1 still at risk, held until co-design |
| 3 | Deck rails 50 x 25 x 2 mm to 60 x 30 x 2 mm | Weld stress range 37.6 MPa (limit 38.8); static factor 2.0; frame 11.4 kg; vehicle 34.0 kg, 36.8 kg with pack; hill 233 W; BOM item 1 $75 | 25.5 MPa; factor 3.0; frame 12.5 kg; vehicle 35.0 kg, 37.9 kg with pack (R10 margin 3.2 to 2.1 kg); hill 235 W (R6 margin 7 to 6 %); item 1 $83 |
| 4 | Key switch in series with the 10 kΩ INTERLOCK coding resistor, standstill use only | Proposed (already modelled and priced) | Decided; wording updated |
| 5 | Raise the legacy-to-heartbeat question with SwapCell | Flag | Cross-repo action (below) |

Files changed: `cad/src/model.py` (rail parameters), STEP and STL re-exported; `cad/src/sheets.py` and SGN-DWG-001 at **Rev P2** (rails and mass notes); `cad/src/concept_media.py` (key figures) and all media regenerated and checked by eye; `docs/04-calcs/sizing.py` (rail section from the model, R12 on the reference build), `results.csv` and SGN-CAL-001 v0.2; `bom/bom.csv` item 1 and `bom/bom-notes.md`; SGN-PRB-001, SGN-PRC-001 and SGN-REQ-001 at v0.5; SGN-DDR-001 v0.2 (item 15 decided); `project.yaml` (DDR-002 in `trl_evidence`); `README.md` (numbers, key components, and new sections Concept rationale, Burning platform, Where it could be used, What sparked the idea); all PDFs re-rendered and every generated file re-rendered with the designmolecule.com footer.

### Requirement status (SGN-CAL-001 v0.2)

- **Not met:** none.
- **At risk:** R1 (1.00 m belt fits a 1.75 m rider only up to 5 km/h; kept until co-design), R6 (235 W for 8 % at 8 km/h, 6 % margin), R10 (37.9 kg with pack, 2.1 kg margin).
- **Not verifiable at TRL 3:** R9 (guard gaps to ISO 13857), R13 (latch class V1 retention).
- **Met on paper:** R2, R3, R4, R5 (45 km), R7, R8, R11, R12 ($546 reference build).

### Still Proposed, awaiting Amish (no recommendation)

- First user group (non-cycling adults, older adults or commuters).
- First target country for the legal category.

### Cross-repo actions

- **SwapCell:** v0.3 does not say whether a pack in legacy discharge moves to mode 2 when a heartbeat arrives; StepGen's logic board, powered from the pack after a key-on wake, needs that. Not edited from this repo.

### Safety

Unchanged from the TRL 3 session, except that the deck-rail weld fatigue concern is closed on paper (still needs a test). R12 now depends on salvaged treadmill and bike parts, whose condition must be checked before use. The key switch cuts the pack without warn-then-derate and is for use at a standstill only.

### TRL 4

TRL 4 remains on hold by Amish's instruction. No test article, test plan, build log, PCB or firmware was created.

## Session 2026-09-25: TRL 3

TRL 3 (analytical proof of concept on paper) is reached and is the hard stop. TRL 4 is on hold by Amish's instruction ("Make sure we don't proceed to TRL 4 on any of them"). The design meets its range, speed, braking, step-off, power and SwapCell interface requirements on paper, but **R12 (cost) is not met** at $713 against the new $650 budget, and R1, R6 and R10 are at risk.

### What was done

- `docs/decisions/0001-trl2-review-decisions.md` (SGN-DDR-001 v0.1): Amish's 2026-09-25 decisions on every TRL 2 review item that had a recommendation, the cross-cutting approvals (SwapCell interface v0.3, shared-pack pricing, co-design partners later), the area move, and the items that stay open.
- `docs/04-calcs/01-sizing.md` (SGN-CAL-001 v0.1) with `docs/04-calcs/sizing.py` and `docs/04-calcs/results.csv`: geometry, mass and centre of mass, road load, energy and range, hill and acceleration, belt drag and belt length, control timing, braking and belt slip, cornering, deck-rail and steering-column strength, SwapCell v0.3 wake and latch class V1, and cost. The script reads the model parameters, the BOM and the budget, and prints every number the note quotes.
- `cad/src/model.py`: parametric build123d model (all key dimensions in `PARAMS`, derived geometry in `geometry()`), exporting `cad/step/stepgen-assembly.step`, `stepgen-frame.step`, `stepgen-deck.step`, `stepgen-receiver.step` and matching STL files in `cad/stl/`. Changes from the TRL 2 massing model: 30 mm fork offset (trail 58 mm instead of about 90 mm), head tube moved back 30 mm so the length stays 2.35 m, 38 mm steering column, class V1 receiver cradle with an over-centre lever, stowed kickstand.
- `cad/src/sheets.py` and `cad/drawings/SGN-DWG-001` (SVG, PDF, PNG): general arrangement at Rev P1, third-angle views at 1:20, isometric view and a key-dimension and interface box, marked "CONCEPT, NOT FOR FABRICATION" and "PRELIMINARY, NOT FOR FABRICATION". SGN-DWG-001 was free; the concept sheet is SGN-DWG-010.
- `cad/src/concept_media.py`: now imports its geometry from `model.py`. All media regenerated and checked by eye: hero, blueprint SGN-DWG-010, cutaway, exploded view (callouts 1 to 15), flow (estimates marked, numbers from SGN-CAL-001), `model.glb` and `viewer.html`. Temporary `media/_views*` folders deleted.
- `bom/bom.csv` and `bom/bom-notes.md`: all 16 lines priced with a supplier or supplier type; pack at $0.00, priced once in SwapCell.
- `docs/01-problem.md`, `docs/02-concept.md`, `docs/03-requirements.md`: decisions recorded, SwapCell interface v0.3, numbers corrected to SGN-CAL-001, new R13 (pack retention to latch class V1), R12 at $650, a status column in the requirements, safety notes added to the problem statement and requirements. **Version note:** these three documents were already at 0.3 from the earlier 2026-09-25 concept change, so they are now at **0.4** (the brief asked for 0.3, which would not be a new version).
- `project.yaml`: `trl: 3`, `trl_target: 3`, `trl_evidence` lists the documents, CAL-001, model, STEP files, drawing and BOM; `area: Mobility and Logistics`; `budget_usd: 650`; the `cleantech` tag removed. Pitch and problem unchanged (no rewording was recommended).
- `README.md`: TRL 3 badge, area, budget, TRL 3 numbers and links to the drawing and sizing note.
- `docs/pdf/`: PDFs of every controlled document at its current version.

### Requirements (SGN-CAL-001, Table 5)

| ID | Status | Value |
| --- | --- | --- |
| R12 cost | **Not met** | $713 excluding the pack against $650; about $538 on a salvage route |
| R1 walking on the belt | At risk | 1.00 m usable, 22 to 30 N push; fits a 1.75 m rider only up to 5 km/h |
| R6 hill | At risk | 233 W for 8 % at 8 km/h, 7 % margin to 250 W |
| R10 size and mass | At risk | 2.35 m, 0.61 m met; 36.8 kg with pack leaves 3.2 kg |
| R9 guards | Not verifiable at TRL 3 | Guards modelled; ISO 13857 gaps need hardware |
| R13 pack retention (class V1) | Not verifiable at TRL 3 | 330 N preload, lever ratio 6.6, bolt factor 22 at 25 g |
| R2 motor only while walking | Met (on paper) | 261 ms belt stop to motor off; 30 ms from brakes or lanyard |
| R3 speed and acceleration | Met (on paper) | 25 km/h cut, 15 km/h mode, 32 N m torque limit for 1.0 m/s² |
| R4 motor class | Met (on paper) | 250 W rated |
| R5 range | Met | 45 km at 20 km/h on the flat (9.1 Wh/km); about 32 km in real use |
| R7 braking | Met (on paper) | 8.0 m from 25 km/h; 9.6 m on the rear brake alone |
| R8 step-off | Met | Belt top 240 mm |
| R11 SwapCell v0.3 | Met (on paper) | 10 kΩ coded INTERLOCK (0.30 V), heartbeat mode 2, 8.5 A maximum |

Other results without a requirement: deck-rail weld fatigue is **at risk** (37.6 MPa walking stress range against a 38.8 MPa limit); the 38 x 2 mm steering column has a factor of 2.0; lean clearance is 30°; belt tension of 500 N per run keeps the belt from slipping under 240 N of braking push.

### Decisions recorded (SGN-DDR-001)

Decided by Amish, 2026-09-25, go with recommendation: two-wheel long-wheelbase form factor (three-wheel open until co-design); 20 in wheels; 250 W rear geared hub, 25 km/h cut, 15 km/h beginner mode; 30 km at 20 km/h range target; no roller generator in the first concept; area Mobility and Logistics; budget $650, pack excluded; confirm the legal category in a first target country before any road use; a decision record. Cross-cutting: SwapCell interface v0.3 (StepGen uses items W and V, not C); shared packs priced once; co-design partners picked per area later.

### Proposed, awaiting Amish

*Update 2026-09-25: items 3 to 7 are now "Decided by Amish, 2026-09-25: go with recommendation" (SGN-DDR-002); items 1 and 2 stay Proposed, awaiting Amish.*

1. **First user group.** Non-cycling adults, older adults or commuters. No recommendation. Still Proposed, awaiting Amish.
2. **First target country** for the legal category. No recommendation. Still Proposed, awaiting Amish.
3. **Cost overrun (R12).** Options: (a) keep $650 and make the salvage route (used walking-pad treadmill, donor 20 in bike; about $538) the reference build, with new parts as fallback; (b) raise `budget_usd` to about $720 for new parts; (c) cut scope (for example drop the display for a simple LED). Recommended: (a). `project.yaml` stays at $650. **Decided by Amish, 2026-09-25: go with recommendation.**
4. **Belt length (R1 against R10).** Options: (a) keep the 1.05 m roller pitch and 2.35 m length until co-design shows the riders' heights and pace; (b) lengthen to about 1.19 m, which fits a 1.90 m rider at 6 km/h but makes the vehicle about 2.49 m and needs R10 relaxed to 2.5 m; (c) cap belt speed in firmware for the short belt. Recommended: (a), revisit after co-design. **Decided by Amish, 2026-09-25: go with recommendation.**
5. **Deck rails.** Change from 50 x 25 x 2 mm to 60 x 30 x 2 mm to take the weld stress range from 37.6 to 25.5 MPa, for 1.08 kg (mass then about 37.9 kg with pack). Recommended. Not applied to the model, because it uses a third of the R10 mass margin. **Decided by Amish, 2026-09-25: go with recommendation;** now applied.
6. **Key switch in the INTERLOCK loop.** Options: (a) a key switch in series with the 10 kΩ coding resistor (off opens the loop and sleeps the pack; on wakes it; also a simple immobiliser); (b) a soft power button that sends a sleep request, with the pack's own wake button to start. Recommended: (a), used at a standstill only. **Decided by Amish, 2026-09-25: go with recommendation.**
7. **Flag to the SwapCell project (not a StepGen decision).** v0.3 does not say whether a pack in legacy discharge moves to mode 2 when a heartbeat arrives, which a host powered from the pack output needs after a key-on wake. **Decided by Amish, 2026-09-25: go with recommendation** (raise with SwapCell; cross-repo action).

### Safety concerns

- Falls on a moving belt, a rider stopping abruptly or leaving the deck at speed: free-running belt, 261 ms motor cut-off, 30 ms lanyard and brake cut, low open deck. Rider dynamics need a test.
- Braking with feet on a belt: the sprag and 500 N belt tension hold the belt; the rider must resist about 240 N at 3 m/s², and harder stops can pitch the rider over the bar.
- Pinch points at both belt nips, the rear tire behind the heel and the spokes: guards modelled, ISO 13857 gaps unverified (R9).
- Weld fatigue at the deck rails is at the limit (proposal 5).
- Pack retention: a pack leaving its cradle at speed is a 2.85 kg projectile with live contacts; class V1 is specified but unverified (R13).
- The key switch cuts the pack at once, without warn-then-derate; use only at a standstill.
- Lithium pack at up to 54.6 V: SwapCell BMS, coded interlock and derating apply; charge only in a dock; 20 A harness fuse. Helmet essential; the rider's head is about 2 m up.
- Legal category unresolved: no road use until it is confirmed in the target country.

### Other notes

- No TRL 4 material exists in the repo (`build-log/` holds only its README; `electronics/` and `firmware/` are empty). None was created.
- The TRL 2 note listed no unchecked citations, and no new citations were added, so no web check was needed.

### Recommended next step

TRL 4 is on hold by Amish's instruction, and this session stops at TRL 3. Next: Amish decides items 1 to 6 above, and the SwapCell project answers item 7. After that, paper work that stays within TRL 3: apply the chosen rail size and belt length to the model and recalculate, and a desk study of the legal category in the chosen country. Co-design sessions with users, once a partner is picked for the area, should come before any hardware.

For the record only, TRL 4 would need: a test article (at least a belt-deck rig and a class V1 receiver cradle), a lab test plan and report (SGN-TST) covering belt drag and walking feel, motor cut-off timing, braking with a standing rider, weld details and V1 vibration and shock, and dated build-log entries. None of this should start until Amish lifts the hold.

## Session 2026-09-25: concept change to a walking-treadmill vehicle (TRL 2)

### Concept change (decided by Amish)

On 2026-09-24 Amish decided that StepGen is a walking-treadmill vehicle, like the Dutch Lopifit walking bike: "as the person walks his scooter / bike moves forward but hes upright walking instead of pedalling". The stationary stepper generator concept of version 0.2, which charged a PowerBox, is dropped entirely. PowerBox therefore loses StepGen as a charging source; the PowerBox repo was not touched in this session. This is the only item in this note recorded as decided. Everything else is proposed, awaiting Amish.

### What was done

- `docs/01-problem.md` (SGN-PRB-001 v0.3): new problem (personal mobility for people who do not cycle), why the belt is a control input and not the engine, users, constraints, legal status in the EU and US with sources, out of scope, prior work (Lopifit, mechanical treadmill bikes, ElliptiGO, scooters), co-design checklist and first-session questions.
- `docs/02-concept.md` (SGN-PRC-001 v0.3): how it works, 15 components numbered to match the exploded view and BOM, key numbers table, why the motor does the work, assist law sketch, SwapCell interface use and gaps, design choices, safety, open questions for TRL 3.
- `docs/03-requirements.md` (SGN-REQ-001 v0.3): the stepper requirements withdrawn and 12 new requirements (R1 to R12) with assumptions and requirements at risk.
- `cad/src/concept_media.py`: new massing model (frame, belt and end rollers, roller bed, anti-reverse clutch, belt speed sensor, 20 in wheels with rear hub motor, fork, steering column, brakes, SwapCell cradle and pack, controller, display and lanyard stop, guards, harness) with a 1.75 m rider standing on the belt mid-stride and holding the bar. A custom two-path flow diagram (energy and control) and a cropped deck cutaway are drawn in the same script. `cad/src/model.py` is still the scaffold placeholder and was not used.
- `media/`: hero, blueprint sheet SGN-DWG-010 (PNG, PDF, SVG), cutaway of the belt deck, exploded view with callouts 1 to 15, energy and control flow (estimates marked), `model.glb` and `viewer.html`. All regenerated; all carry "CONCEPT, NOT FOR FABRICATION".
- `bom/bom.csv` and `bom/bom-notes.md`: new 16-line BOM, items 1 to 15 matching the exploded view; the SwapCell pack is listed at $0.00 and excluded from the total, as in PowerBox.
- `project.yaml`: new `pitch`, `problem` (with the co-design sentence) and tags. `area`, `budget_usd`, `trl` and `trl_target` unchanged.
- `README.md`: pitch, problem, key components, safety and hero caption updated; hero image and links line kept before "Problem".
- `docs/pdf/`: PDFs of the three documents at v0.3.
- `docs/04-calcs/` holds only `.gitkeep`, so there were no stepper calculations to update. `docs/decisions/` holds only the template, so there was no stepper decision record to supersede and no new record was added (see suggestions).

### Key results (estimates, to be checked at TRL 3)

Assumptions: 80 kg rider, about 35 kg vehicle, 2.8 kg pack (about 118 kg total), Crr 0.010, CdA 0.70 m², motor 80 % and controller 95 % efficient, about 410 Wh usable from one SwapCell pack.

| Quantity | Estimate | Requirement |
| --- | --- | --- |
| Walking speed on the belt | 4 to 6 km/h | R1 |
| Rider push and power into the belt | 15 to 30 N, about 20 to 40 W (all spent as belt drag) | R1 (30 N) met |
| Vehicle speed | Up to 25 km/h; 15 km/h beginner mode; about 20 km/h cruise | R3 met by design |
| Motor | 250 W rated rear geared hub; about 136 W at the wheel at 20 km/h, 221 W at 25 km/h | R4 met |
| Pack draw | About 179 W (3.8 A) at 20 km/h; about 291 W (6.2 A) at 25 km/h; 15 A limit | R11 met |
| Energy per km | About 6.9, 9.0 and 11.6 Wh/km at 15, 20 and 25 km/h | |
| Range per SwapCell pack | About 60, 46 and 35 km at 15, 20 and 25 km/h on the flat; perhaps 25 to 35 km in real use | R5 (30 km at 20 km/h) met |
| Hill | 8 % at 8 km/h needs about 236 W at the wheel | R6 met, thin margin |
| Mass | About 35 kg without the pack, 38 kg with it | R10 (40 kg) met, thin margin |
| Size | About 2.35 m long, 0.62 m wide, belt top 240 mm above the ground, belt 1.05 m by 400 mm | R8, R10 met; length margin thin |
| Braking | About 8 m from 25 km/h at 3 m/s² | R7 met on paper |
| Optional roller generator | About 5 to 10 W back to the pack for about 15 W more walking effort; about 5 % more range | Not recommended now |
| Mechanical belt drive (for comparison) | About 7 to 9 km/h at best on the flat; stalls on a 3 % grade | Why the motor does the work |
| Parts cost | About $630 excluding the SwapCell pack (pack about $370 more) | R12 ($400) **not met** |

Requirements not met or at risk:

- **R12 (cost) is not met.** About $630 excluding the pack, about $230 over $400. Salvaged treadmill and bike parts might bring it to about $450 to $500, still over budget.
- **R6 and R10** are met with thin margins (hill power close to the 250 W rating; length 2.35 m against 2.4 m; mass 38 kg against 40 kg).
- **Legal category is unresolved.** EU pedelec rules and US e-bike definitions both assume pedals. The design follows EU pedelec limits, but that may not be enough for road use.
- **R11** depends on SwapCell choices that are still open (connector family, latch vibration rating, CAN bit layout).

### Proposed, awaiting Amish

*Update 2026-09-25: items 1 to 8 were decided by Amish on 2026-09-25 (go with recommendation, SGN-DDR-001); item 9 (first user group) stays Proposed, awaiting Amish.*

1. **Form factor.** Recommended: two-wheel, long-wheelbase, bike type (about 2.35 m, like the Lopifit), because a natural stride needs about 1.0 m of belt. Alternatives: a compact scooter type (short belt, shuffling steps, small wheels) or a three-wheel tadpole (stable at rest for non-cyclists, but wider and heavier). Keep the three-wheel option open until co-design.
2. **Wheels.** Recommended: 20 in front and rear. Alternatives: 28 in front with 20 in rear (Lopifit layout) or 16 in all round.
3. **Motor and speed class.** Recommended: 250 W rated rear geared hub, assist cut at 25 km/h, 15 km/h beginner mode (EU pedelec limits). Alternatives: US class 1 style 32 km/h (20 mph) with 500 to 750 W, or a 20 km/h cap throughout.
4. **Target range.** Recommended: 30 km at 20 km/h on the flat on one SwapCell pack (R5). Alternative: a double pack for longer trips, which SwapCell lists only as a later variant.
5. **Regeneration option.** Recommended: no roller generator in the first concept; keep a mounting point on the front roller. It returns only about 5 to 10 W and needs a SwapCell charge-while-driving mode that does not exist.
6. **Area.** Proposed: move `area` from CleanTech to Mobility and Logistics, matching SunSpoke and WaterWalker. `project.yaml` still says CleanTech.
7. **Budget.** Proposed: raise `budget_usd` from $400 to about $650 (pack excluded). Alternative: keep $400 and design around a salvaged treadmill and a donor bike, which the estimate suggests would still land at about $450 to $500. `project.yaml` still says $400.
8. **Legal route.** Proposed: pick a first target country and confirm the vehicle's legal category there before any road use.
9. **First user group and partner.** Non-cycling adults, older adults or commuters.

### Safety concerns

- Falls on a moving belt: stumbling, stopping walking abruptly, and a rider leaving the deck at speed. Free-running belt, 0.5 s motor cut-off, lanyard stop, low open deck and handlebar are the controls; rider dynamics need a TRL 3 study.
- Braking with feet on a belt: without the anti-reverse clutch the feet would slide forward. Hard braking can pitch a standing rider over the bar.
- Pinch points: belt in-running nips at both rollers, the rear tire behind the heel, spokes, and clothing such as long skirts. Guards to ISO 13857 reach distances.
- Speed and height: 25 km/h limit and a beginner mode; the rider's head is about 2 m up, so a helmet is essential.
- Stability of a standing rider in turns and when parked; kickstand needed.
- Lithium pack at up to 54.6 V: SwapCell BMS, interlock and warn-then-derate rules apply; charge only in a dock; 20 A harness fuse.

### Suggestions (not done)

- Add a design decision record (`docs/decisions/0001-...`) for the concept change, if Amish wants one; the prompt asked for it only if a stepper record already existed.
- Tell the SwapCell project about the two gaps StepGen hits: latch vibration rating for vehicles, and charging from a vehicle while driving.

### Recommended next step

Review this note and the media, and decide the proposed items above, especially form factor, speed class, budget and area. Start co-design with non-cycling users before `/advance-trl3`, since balance and step-off may change the form factor. If approved, `/advance-trl3` should do the calculation note (road load and range, hill and acceleration, belt drag and roller bed, braking and rider dynamics, frame loads and steering geometry, stability), the parametric model with STEP export and drawing sheet, and a fully priced BOM.

## Session 2026-09-27: kit 1.5.0 and image quality

- Kit 1.5.0 synced: STANDARDS v1.5 (sections 12 to 15: product renders, storefront images and image quality, public release, authorship and signing), `.kit/cards.py`, `.kit/image_qc.py`, `.kit/release_gate.py`, issue templates, and the `/render-product` and `/release` commands. `CLAUDE.md` now matches `.kit/CLAUDE.md`.
- Every `media/render-*.png` recaptioned from its original render with the new layout: the title, concept label and repository sit in a band above the render and the view note in a band below it, each line wrapped to the image width, so no text overlaps other text or the render or runs off the image. `media/card.png` and `media/social-preview.png` regenerated with the same rules.
- `python .kit/image_qc.py` and `python .kit/release_gate.py` pass. trl stays 3.

## Session 2026-10-02: approved follow-ups carried out

Amish approved all follow-up actions from the open-decision sign-off on 2026-10-02. No CAD model, calculation result, drawing or build plan picture changed.

### Approved follow-ups carried out

1. Decision 5, BOM: done. `bom/bom-notes.md` records that the rotor carriers on the rear and front hubs (lines 6 and 7) are confirmed against the hubs bought when the wheel build is specified. No quantity or price changed.
2. Decision 6, pictures: appearance model done. The "250 W 25 km/h" rating decal is removed from `cad/src/product_model.py`; render scenes exported to `/home/claude/renders/stepgen` for the views hero, exploded and detail (one .npz and .json each, plus `stepgen__jobs.json`). Not done here: the photoreal renders, `media/card.png` and `media/social-preview.png` are made on Amish's Mac next.
3. Decision 3, calculations: not done, the RDW check has not happened (outreach by Amish). R3 and R4 stay as they are until it sets a lower speed cap or requires type approval.

### Results

- Requirement status changes: none.
- Value-engineering target: USD 650. Estimated cost of the constructable design: USD 610 on the reference build (USD 40 under the target). `budget_usd` is unchanged. Mass is unchanged.

### Documents changed

No controlled document changed, so no version was bumped. Files changed: `cad/src/product_model.py`, `bom/bom-notes.md`.

### Cross-repo actions

None.

## 2026-10-02: photoreal renders redone on the constructable design

Rendered with Blender Cycles on Amish's Mac from the updated appearance model; captioned with `.kit/photo_caption.py`; `media/card.png` and `media/social-preview.png` regenerated with `.kit/cards.py`. Views: hero, exploded, detail. image_qc passes. Appearance deviations are those logged above as proposed, awaiting Amish.

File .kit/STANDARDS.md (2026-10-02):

---
doc_id: OHP-STD-001
title: Documentation and drawing standard
project: Open Hardware Portfolio
doc_type: Standard
version: "1.7"
status: Released
date: 2026-09-30
author: Amish Chadha
license: CC-BY-SA-4.0
revisions:
  - version: "1.0"
    date: 2026-09-24
    author: Amish Chadha
    change: First release of the standard
  - version: "1.1"
    date: 2026-09-24
    author: Amish Chadha
    change: Adopt Technology Readiness Levels (section 9) for project maturity
  - version: "1.2"
    date: 2026-09-24
    author: Amish Chadha
    change: Portfolio phase cap (section 10), concept media standard (section 11), CLAUDE.md guardrails
  - version: "1.3"
    date: 2026-09-24
    author: Amish Chadha
    change: Scale figure, interactive 3D viewer and flow diagrams added to concept media; session slash commands
  - version: "1.4"
    date: 2026-09-26
    author: Amish Chadha
    change: Every sheet and render names the project and its GitHub repository; overall dimensions, ISO centre lines and 300 dpi PNG on sheets; titles name the device and view labels state the viewing direction; optional photoreal renders with Blender
  - version: "1.5"
    date: 2026-09-27
    author: Amish Chadha
    change: Product renders (section 12), storefront images and image quality check (section 13), public release and release gate (section 14), authorship, citation and commit signing (section 15)
  - version: "1.6"
    date: 2026-09-29
    author: Amish Chadha
    change: Licensing metadata with REUSE (section 16), Zenodo DOI and Software Heritage archiving (section 17), release gate checks REUSE and a single CITATION.cff license, archive.py
  - version: "1.7"
    date: 2026-09-30
    author: Amish Chadha
    change: Concept and constructable design states; design decisions register (DEC) kept apart from the build plan; prototype build plan (BLD, section 18) with pictures by component is required TRL 3 evidence; every repo targets TRL 3 during the populate phase; build_views.py; /to-trl3 and /build-plan commands
---

# Documentation and drawing standard

Every project in the portfolio uses this standard, so that each precis, write-up and sketch looks the same and carries its own version history. The standard ships as a kit in each repo's `.kit/` folder. The kit version is in `.kit/KIT_VERSION`.

## 1. Document types and IDs

Every controlled document has a unique ID in the form `PRJ-TYP-NNN`.

- `PRJ` is the three-letter project code listed in section 7.
- `TYP` is the document type code from the table below.
- `NNN` is a sequence number within that project and type, starting at 001.

| Code | Type | Typical file |
| --- | --- | --- |
| PRC | Design precis | `docs/02-concept.md` |
| PRB | Problem statement | `docs/01-problem.md` |
| REQ | Requirements | `docs/03-requirements.md` |
| CAL | Calculation or sizing note | `docs/04-calcs/*.md` |
| DDR | Design decision record | `docs/decisions/*.md` |
| BOM | Bill of materials | `bom/bom.csv` |
| DWG | Drawing or sketch sheet | `cad/drawings/*.svg` |
| BLD | Prototype build plan (section 18) | `docs/05-build-plan.md` |
| DEC | Design decisions register (section 18) | `docs/06-design-decisions.md` |
| TST | Test plan or test report (front matter adds `environment: lab` or `relevant`) | `docs/05-tests/*.md` |

Example: `TBK-PRC-001` is the ThermaBrick design precis.

## 2. Revision scheme

| Artifact | While in draft | When released | Change after release |
| --- | --- | --- | --- |
| Documents | 0.1, 0.2, 0.3 ... | 1.0 | 1.1 for minor edits, 2.0 for a design change |
| Drawings | Rev P1, P2 ... (preliminary) | Rev A | Rev B, C ... |

- Every change to a controlled document adds a row to its revision history before the commit.
- The `version` field in front matter always equals the newest row in `revisions`. The renderer rejects a document where they differ.
- Status is one of `Draft`, `In review`, `Released` or `Superseded`. Draft and In review documents print with a status band on every page.
- Every release is tagged in Git as `<doc_id>/v<version>`, for example `TBK-PRC-001/v1.0`. Drawings are tagged `TBK-DWG-001/revA`.
- Git history is the full audit trail. The in-document revision table is the human-readable summary.

## 3. Document front matter

Every Markdown document under version control starts with this block:

```yaml
---
doc_id: TBK-PRC-001
title: ThermaBrick design precis
project: ThermaBrick
doc_type: Precis
version: "0.1"
status: Draft
date: 2026-09-24
author: Amish Chadha
license: CERN-OHL-S-2.0
revisions:
  - version: "0.1"
    date: 2026-09-24
    author: Amish Chadha
    change: Initial draft
---
```

Quote version numbers so YAML keeps `1.0` as text instead of turning it into a number. List revisions newest last.

## 4. Writing style

- Chicago Manual of Style.
- No em dashes. Restructure the sentence instead.
- Lead each section with its conclusion, then support it.
- SI units throughout, in the form `12 kW`, `450 °C`, `3.2 m`. Imperial values may follow in parentheses.
- Number every figure and table ("Figure 2", "Table 1") and give each a caption.
- State every assumption in the calculation that depends on it.
- Put safety notes in a blockquote starting with **Safety:**.

## 5. Visual identity

| Element | Specification |
| --- | --- |
| Typeface | IBM Plex Sans for text, IBM Plex Mono for code and values (SIL Open Font License, bundled in `.kit/fonts`) |
| Ink | `#111827` |
| Secondary text | `#4B5563` |
| Rules and grid | `#D1D5DB` |
| Accent (one only) | `#0F766E` teal |
| Document page | US Letter, 20 mm margins |
| Drawing sheet | ANSI B landscape (431.8 x 279.4 mm) |
| Footer | Document ID, version, status, license and designmolecule.com on every page |

## 6. Drawing and sketch conventions

- Units are millimeters unless the title block says otherwise.
- Third-angle projection, marked with the symbol in the title block.
- Line weights: visible outlines 0.5 mm, hidden lines 0.25 mm dashed, center lines 0.18 mm chain.
- The title block contains the project, title, drawing number, revision, scale, units, projection, sheet, author, date, material or notes, and license.
- Every sheet and every render names the project and its GitHub repository (from `repo:` in `project.yaml`), at the top of the sheet and in the title block, so a printed or forwarded sheet is never anonymous.
- The drawing title names the device, not only the drawing type (for example "Handheld near-infrared resin scanner: general arrangement").
- Every view label states its scale and viewing direction (for example "Scale 1:1; side elevation looking along +Y"), and every isometric or render states where it is seen from.
- Orthographic views generated with `add_ortho` carry overall dimensions (length and depth on the top view, height on the front view) and ISO 128 centre lines on cylinders; hidden lines are dashed. Tolerances are not shown before TRL 4.
- Sheets are exported as SVG, PDF and a 300 dpi PNG.
- The revision table in the top right of the sheet lists every revision.
- Concept sketches use the same sheet and title block and carry the label "CONCEPT, NOT FOR FABRICATION".
- Geometry comes from `cad/src/*.py` (build123d). Sheets are generated by `.kit/drawing.py` and never edited by hand.

## 7. Project codes

| Code | Project | Code | Project | Code | Project |
| --- | --- | --- | --- | --- | --- |
| TBK | ThermaBrick | PCF | PicoFlow | HLT | HelioLite |
| CCB | CharCube | DRN | DustRunner | TRT | TremorTrace |
| STC | StepCue | FXH | FlexHand | CPD | ColdPod |
| SCL | SunClave | STR | SteamRoot | GGD | GrainGuard |
| SDL | SeedLine | ZBX | ZeerBox | RMS | RootMesh |
| DWD | DewDrive | SSK | StillStack | PPR | PotPress |
| WWT | WaterWatch | LMF | LumaFlow | FCL | FieldCell |
| CNP | ConePro | CVC | CulvertCrawl | EGD | EmberGuard |
| SNF | SnapFrame | CGM | CargoMule | SCM | StepClimber |
| SWC | SwapCell | PLP | PalletPilot | FTK | FlatTrike |
| WWK | WaterWalker | GRR | GrowRider | SSP | SunSpoke |
| SGN | StepGen | PBX | PowerBox | WML | WasteWise-ml |
| WSC | WasteWise Scan | RFE | ReflowEconomy | | |
| OHP | Portfolio-wide | | | | |

## 8. Build and publish

- `python .kit/render.py` checks every controlled document and renders it to `docs/pdf/<doc_id>_v<version>.pdf`.
- `python .kit/drawing.py` (called from each project's `cad/src/sheets.py`) builds drawing sheets as SVG and PDF in `cad/drawings/`.
- The GitHub Action in `.github/workflows/docs.yml` runs the checks on every push and attaches PDFs to a GitHub Release whenever a release tag is pushed.
- Public releases follow section 14: `python .kit/release_gate.py` must pass, and the release tag is `v0.<TRL>.0` (for example `v0.3.0` at TRL 3).

## 9. Technology Readiness Level (TRL)

Each project states its maturity as a Technology Readiness Level on the NASA and US DOE 1 to 9 scale. The TRL rates this specific design, not the underlying technology. A sand battery is commercial elsewhere, but a new sand battery design starts at TRL 2 until evidence shows otherwise.

| TRL | Definition | Evidence the repo must contain |
| --- | --- | --- |
| 1 | Basic principles observed | Problem statement (PRB) |
| 2 | Technology concept formulated | Draft precis (PRC) and requirements (REQ) |
| 3 | Analytical or experimental proof of concept | Calculation note (CAL), working build123d model with STEP export, drawing sheet (DWG), priced BOM with every unit cost filled in, prototype build plan (BLD) with pictures, `design_state: constructable` |
| 4 | Components validated in the lab | Test report (TST) with `environment: lab`, build log entries |
| 5 | Validated in a relevant environment | Test report (TST) with `environment: relevant` |
| 6 | System prototype demonstrated in a relevant environment | Precis at version 1.0 or later with status Released, a drawing at a lettered revision (Rev A or later), and a system-level TST with `environment: relevant` |
| 7 to 9 | Operational demonstration through proven in service | Beyond portfolio scope; claim only with a named deployment partner and evidence |

Rules:

- `project.yaml` records `trl` (current level), `trl_target` (the level the current effort aims for) and `trl_evidence` (the files that support the claim).
- `python .kit/render.py --check` fails if the evidence for the claimed TRL is missing. CI runs this check on every push.
- Documentation alone cannot go past TRL 3. TRL 4 and above require hardware and a test report.
- TRL and visibility are independent. A repo can be public at TRL 3 as a documented design ready to build.
- A change of TRL is recorded in the build log with the date and the evidence that justified it.

## 10. Portfolio phase and TRL cap

`.kit/PHASE.yaml` sets the current phase. During the **populate** phase every repo is capped at **TRL 3**: `trl` and `trl_target` may not exceed 3, and the check fails if they do. Every repo targets the cap: `trl_target` must equal 3, so a new repo is taken all the way to TRL 3 (scaffold, populate and advance, see `/to-trl3`). Work that belongs to TRL 4 or later (building or testing hardware, test articles, test plans and reports, build-log entries, purchasing lists, PCB layouts) must not be started. The prototype build plan (BLD, section 18) is TRL 3 paper work and is required. Where it already exists it is kept, flagged in the check output, and not extended. Only Amish changes `PHASE.yaml`.

Every repo carries a `CLAUDE.md` with the working rules for AI sessions: the TRL cap, decision rights (nothing is recorded as decided unless Amish decided it), one step per session, and a mandatory `docs/REVIEW.md` before stopping.

## 11. Concept media

Every repo at TRL 2 or above explains its idea visually. Media are generated from a build123d massing model with `.kit/concept.py`, never drawn by hand, so they stay in step with the design.

| File | Required | Purpose |
| --- | --- | --- |
| `media/hero.png` | TRL 2+ | Shaded isometric render with a 1.75 m person for scale; the website card image |
| `media/concept-blueprint.png` and `.pdf` | TRL 2+ | Blueprint concept sheet: orthographic and isometric views, scale, key figures, title block |
| `media/model.glb` and `media/viewer.html` | TRL 2+ | Interactive 3D viewer (glTF plus model-viewer) for the website |
| `media/cutaway.png` | When the inside matters | Section view showing internal parts |
| `media/exploded.png` | Recommended | Exploded view with numbered callouts matching the BOM |
| `media/flow.png` | When energy or material moves | System, energy or material flow diagram with losses |

Session commands in `.claude/commands/` (`/populate`, `/advance-trl3`, `/rein-in`, `/refresh-media`) carry the standard prompts, so every Claude Code session starts from the same instructions.

At TRL 2 a massing model is enough: correct overall proportions and main components. All concept media carry "CONCEPT, NOT FOR FABRICATION". The check warns when required media are missing at TRL 2 and fails at TRL 3.

## 12. Product renders

Every repo at TRL 3 shows the product as it would look, not only as a massing model.

- `cad/src/product_model.py` is the appearance model. It defines `product_parts()` (named parts with a shape and a material), `TITLE` ("Name: what it is") and `RENDER_VIEWS`. It is for renders only: every main dimension comes from `cad/src/model.py`, never typed in again.
- Where the appearance model departs from `model.py` (a chamfer, a label, a fastener drawn for realism), record the deviation in `docs/REVIEW.md` as "Proposed, awaiting Amish".
- Scale comes from context, not from a floating figure: a hand or forearm for handheld objects, and the posed mannequin (`mannequin()` in `.kit/context_parts.py`: stand, walk, push, ride, sit, reach) for anything a person uses at body scale.
- Renders are made with `.kit/export_views.py` (one scene per view) and `.kit/photoreal.py` (Blender Cycles), then captioned with `.kit/photo_caption.py`. Files are `media/render-<view>.png`; `media/render-hero.png` is required.
- Every caption names the project, the repository and the viewing direction, and carries "CONCEPT, NOT FOR FABRICATION".
- Captions never sit on the render. `.kit/photo_caption.py` adds a header band (title, concept label, repository) above the render and a footer band (view note) below it, wraps every line to the image width, and steps the font down to a floor before adding a line.
- The README opens with `media/render-hero.png`.
- Software-only and scene repositories (no single product) may use a scene render as the hero instead of a product model.

## 13. Storefront images

Two images, both made from `media/render-hero.png` by `python .kit/cards.py .`:

| File | Size | Purpose |
| --- | --- | --- |
| `media/card.png` | 800 x 800 | Square thumbnail for the organization profile page |
| `media/social-preview.png` | 1280 x 640, under 1 MB | GitHub social preview, shown when a repository link is shared |

- The social preview shows the area, name, one-line description, the first sentence of the pitch, the brand line and the repository address. Design Molecule repos read "Design Molecule · open hardware concept, TRL n"; OpenRatio repos read "OpenRatio · research and educational prototype, TRL n".
- GitHub has no API for the social preview. Upload it under the repository's Settings, Social preview, on release day.
- Regenerate both images whenever `render-hero.png` changes.

### Image quality

Every render, card and social preview must be clear and readable. `python .kit/image_qc.py` checks each one, and the release gate blocks on any failure:

| Check | Rule |
| --- | --- |
| Layout | Made by the current `photo_caption.py` or `cards.py`, which store the text layout in the PNG |
| Text inside the image | Every line at least 1.2 % of the image width from each edge; nothing runs off the side |
| No overlap | No line of text touches another line, and no caption text sits on the render |
| Text size | Render captions at least 1.05 % of the image width in pixel height (17 px at 1600 px); social preview text at least 16 px |
| Resolution | Renders at least 1200 px wide; card 800 x 800; social preview 1280 x 640 and under 1 MB |
| Sharpness | The render is not blurred or upscaled (edge sharpness at least 15 on the `image_qc.py` scale) |

Long titles and notes wrap to more lines rather than shrinking below the floor. The social preview shortens the pitch sentence with an ellipsis only if it cannot fit at the smallest size.

## 14. Public release

A repository goes public only when Amish approves it, and only after `python .kit/release_gate.py` passes. The gate checks:

1. `render.py --check` passes (document control, TRL cap, concept media).
2. Storefront: hero render, card, social preview under 1 MB, README leading with the hero, and every image passing the image quality check (section 13).
3. Issue templates in `.github/ISSUE_TEMPLATE/`: question, build report, design suggestion. The build report template restates that the design is a TRL 3 concept, not released for fabrication (OpenRatio: a research and educational prototype, not a medical device).
4. `CITATION.cff` valid, with an author ORCID.
5. License files match `project.yaml`.
6. No em dashes in the repository's own text.
7. BioMedical and OpenRatio repos use soft, non-clinical wording: "research and educational prototype, not a medical device".
8. No secrets anywhere in the history (gitleaks).
9. No links to sibling repositories that are still private.
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

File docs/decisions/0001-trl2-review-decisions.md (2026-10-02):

---
doc_id: SGN-DDR-001
title: StepGen TRL 2 review decisions
project: StepGen
doc_type: Design decision record
version: "0.3"
status: Draft
date: '2026-10-02'
author: Amish Chadha
license: CERN-OHL-S-2.0
revisions:
- version: "0.1"
  date: '2026-09-25'
  author: Amish Chadha
  change: Record Amish's 2026-09-25 decisions on the TRL 2 review, the move to SwapCell interface v0.3 and the items that stay open
- version: "0.2"
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

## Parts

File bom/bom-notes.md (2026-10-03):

# BOM notes

Every line in `bom/bom.csv` is priced (TRL 3). Prices are estimates for one-off purchase in 2026 US dollars, with a supplier or supplier type; they are not quotes. Item numbers 1 to 15 match the exploded view (`media/exploded.png`), the components table in SGN-PRC-001 and the model in `cad/src/model.py`; item 16 (hardware, kickstand and consumables) has no callout. The totals below are printed by `docs/04-calcs/sizing.py` (SGN-CAL-001), which reads this BOM and the budget in `project.yaml`.

**The SwapCell pack (item 11) is not included in the total.** By Amish's 2026-09-25 portfolio rule a shared SwapCell pack is priced once, in the SwapCell BOM (about $414 in prototype parts), and excluded from each dependent kit budget. It is listed at $0.00 so the numbering matches the exploded view.

| Group | Items | Cost (new parts) |
| --- | --- | --- |
| Frame, deck and belt | 1 to 5 | $264 |
| Wheels, motor, steering and brakes | 6 to 9 | $266 |
| SwapCell receiver (class V1), electrics and guards | 10, 12 to 15 | $178 |
| Hardware, kickstand and consumables | 16 | $42 |
| **StepGen total, all new parts, pack excluded** | 1 to 10, 12 to 16 | **$750** |
| **Reference build (salvage route), pack excluded** | items 2 and 3 from a walking pad, the front wheel and item 9 from a donor bike, fork and headset new | **$610** |
| SwapCell pack (not in total) | 11 | about $414, SwapCell BOM |

**Value engineering.** `budget_usd` ($650) is a hypothetical value-engineering target, not a limit (Amish, 2026-10-01). Value-engineering target: USD 650. Estimated cost of the constructable design: USD 610 on the reference build (USD 40 under the target); USD 750 with all new parts (USD 100 over the target).

**Reference build.** Amish decided on 2026-09-25 (SGN-DDR-002) to make the salvage route the reference build, with new parts as the fallback. A used walking-pad treadmill supplies items 2 and 3 (about $40 instead of $150) and a donor 20 in bike supplies the front wheel and the brakes (about $50 instead of $120 for items 7 and 9). The donor's 20 in fork is too short for StepGen's head tube (SGN-DDR-003), so the fork and headset are bought new (about $40). The salvage prices are estimates and depend on the local second-hand market.

Changes for construction (SGN-DDR-003, 2026-10-01): item 1 restated as a welded frame with a nose beam, two cross members under the rails, four stays, a bought machined ZS44 head tube and welded plates ($83 to $92); item 2 adds axle bolts and tension bolts ($95 to $97); item 3 has aluminium carrier bars and rivet nuts ($50 to $53); item 4 is a one-way bearing inside the rear roller and a drag screw ($20 to $15); item 5 adds a bracket ($6 to $7); item 7 is a 26 in size fork on the 20 in wheel; item 8 is a welded column that clamps the steerer and a straight 580 mm bar ($32 to $36); item 14 adds flanges, spacers and a bought fender ($32 to $42); item 15 adds grommets ($16 to $17); item 16 adds rivet nuts ($38 to $42).

Changes since TRL 2 ($630): the receiver cradle now meets SwapCell latch class V1 with an over-centre lever, a floating receptacle, the 10 kΩ INTERLOCK coding resistor and a key switch (item 10, $22 to $55, and item 13; the key switch was decided by Amish on 2026-09-25, SGN-DDR-002); the motor is specified for a 20 in wheel and the wheel build is priced separately (item 6, $95 to $110); the fork has a 30 mm offset (item 7, $60 to $70); a kickstand is added (item 16); the deck rails grow from 50 x 25 x 2 mm to 60 x 30 x 2 mm for weld fatigue (item 1, $75 to $83, SGN-DDR-002).

The optional belt-roller generator (see SGN-PRC-001) is not in this BOM. It would add about $35 to $50 (a small BLDC motor, rectifier and boost stage) and is not in the first concept (decided by Amish, 2026-09-25).

Rotor carriers (decision of 2026-10-02): the 28 laced spokes and the rotor carriers on the wheels are appearance only. When the wheel build is specified, the 6-bolt carrier on the rear hub (line 6) and on the front hub (line 7) is confirmed against the hub bought, together with the 160 mm rotors (line 9). No quantity or price changed.

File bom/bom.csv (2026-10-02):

Item | qty | spec | supplier | unit_cost_usd | make_buy | notes
1 Main frame | 1 | Mild steel (S235 class) weldment: two 60 x 30 x 2 mm RHS deck rails 1.15 m long on edge (SGN-DDR-002) with 3 mm end caps; two 25 x 25 x 2 mm cross members 500 mm long welded under the rails; 60 x 40 x 2 mm nose beam 500 mm across the rail fronts; 44 x 2 mm down tube mitred to the nose beam and to the head tube 100 mm above its bottom; bought steel head tube 50 x 3 mm x 150 mm machined for a ZS44 headset at 70 degrees; four 22 x 1.6 mm rear stays to 6 mm dropout plates 135 mm apart with slots open downward and a caliper tab on the left; tension lugs, front axle crush sleeves, drag screw nut, kickstand plate, controller plate and two cradle tabs welded on; painted | Local steel stockist; machined head tube from a frame-builder supplier; welding by the builder or a local welder | 92.00 | make | Estimate (SGN-DDR-003): tube and RHS about $40, machined head tube $25, plates and small parts $12, paint and welding consumables $15; about 12.9 kg (SGN-CAL-001)
2 Belt and end rollers | 1 | 400 mm wide treadmill belt loop about 2.2 m; two 50 mm crowned end rollers 420 mm long on fixed 17 mm axles with 6203 size bearings, 1.05 m apart; front axle held by two M10 bolts; rear axle in slots with two M8 x 60 mm tension bolts set to about 500 N per run; spacers | Treadmill spare-parts supplier | 97.00 | buy | Estimate for new parts; a salvaged walking-pad treadmill can supply items 2 and 3 for about $40 (SGN-CAL-001); roller length and bearing size to be confirmed on the donor
3 Roller bed | 1 | 14 gravity conveyor rollers 30 mm diameter by 410 mm with 8 mm spring axles, at 70 mm pitch; two 50 x 3 mm aluminium carrier bars 970 mm long fixed inside the deck rails by four M6 screws each into rivet nuts | Conveyor parts supplier; aluminium bar from a metal stockist | 53.00 | buy | Estimate; rollers about $3 each, carrier bars and rivet nuts $11; keeps belt drag near 22 N
4 Anti-reverse bearing and belt drag | 1 | One-way (sprag) bearing, CSK17 class (17 x 40 x 12 mm, same size as a 6203), pressed into the right end of the rear roller in place of its plain bearing, so the belt can only run rearward; M8 thumb screw with a felt tip through the right rail onto the rear roller end for an adjustable drag of 0 to 8 N at the belt | Bearing distributor; hardware store | 15.00 | buy | Estimate (SGN-DDR-003); holds the belt against about 240 N of rider push when braking (6 N m against about 56 N m rated)
5 Belt speed sensor | 1 | Hall sensor on a 2.5 mm bracket inside the left rail, reading an 8-magnet ring glued to the left end face of the front roller (about 20 mm of belt per pulse), sealed cable through a grommet | E-bike parts supplier | 7.00 | buy | Estimate; same parts as a pedal-assist sensor
6 Rear wheel with 250 W geared hub motor | 1 | 48 V 250 W rated geared hub motor wound for a 20 in wheel (about 400 rpm no-load at 48 V; 32 N m or more peak), 135 mm dropout, laced into a 20 in (ETRTO 406) rim with 20 x 1.75 in tire and tube, torque arms both sides | E-bike motor distributor; rim spokes and tire from the local bike trade | 110.00 | buy | Estimate: motor about $75 and wheel build about $35; motor class decided by Amish 2026-09-25
7 Front wheel fork and headset | 1 | 20 in front wheel with 6-bolt disc hub (100 mm), tire and tube; 1 1/8 in threadless steel rigid fork with post-mount disc tabs, axle to crown about 410 mm (26 in size), 30 mm offset, steerer at least 220 mm; ZS44 semi-integrated headset | Bicycle shop or bicycle parts distributor | 70.00 | buy | Estimate: wheel $30, fork $32, headset $8; a donor 20 in bike can supply the front wheel and item 9 for about $50, but its fork is too short for the head tube, so the fork and headset are bought (about $40; SGN-DDR-003)
8 Steering column handlebar and grips | 1 | Welded steering column: 33.7 x 2.3 mm clamp sleeve 80 mm long, slotted, with two M6 clamp lugs on the 1 1/8 in steerer; 38 x 2 mm column to a 1.23 m bar height; 30 x 2 mm stem 53 mm long; 26.9 x 2.3 mm bar clamp with two M6 bolts; 580 mm straight 22.2 mm steel or aluminium flat bar; grips | Local steel stockist and bicycle shop | 36.00 | make | Estimate; column sized for a 500 N push at the bar (SGN-CAL-001)
9 Brakes with motor cut-off levers | 1 | Two mechanical disc brakes for 160 mm rotors (front on the fork post mount, rear on the left dropout tab), two 6-bolt 160 mm rotors, two levers with built-in motor cut-off switches, cables | Bicycle or e-bike parts supplier | 50.00 | buy | Estimate; either brake alone stops from 25 km/h in about 9.6 m or less
10 SwapCell receiver cradle class V1 | 1 | SwapCell interface v0.3 vehicle receiver: folded 3 mm steel cradle (base, side guides with 1 mm clearance per side, lower end stop with blind-mate receptacle on a floating mount); over-centre lever on a pin between the guide ears, its pad pressing the pack handle end, giving 330 N or more preload (ratio 6.6 or more, hand force 50 N or less); 10 kOhm +/-1 % INTERLOCK coding resistor in series with the key switch; two M6 bolts to the welded tabs | Local fabricator plus connector distributor | 55.00 | make | Estimate: cradle $12 lever $8 receptacle $30 resistor and hardware $5
11 SwapCell pack | 1 | SwapCell interface v0.3: 13S2P 21700 lithium-ion, 46.8 V nominal, about 468 Wh, 340 x 90 x 80 mm, about 2.85 kg | SwapCell project | 0.00 | make | NOT INCLUDED in the StepGen total; priced once in the SwapCell BOM (about $414) by Amish's 2026-09-25 portfolio rule
12 Controller and walking logic board | 1 | 48 V (to 54.6 V) 15 A sine-wave hub motor controller with brake-cut and speed-command inputs, in a box no larger than 150 x 70 x 40 mm, bolted to the plate on the left of the down tube; ESP32 board with CAN transceiver and 60 V input buck converter, acting as the SwapCell host (vehicle heartbeat requesting discharge) and reading belt speed brakes and lanyard | E-bike parts supplier and electronics distributor | 40.00 | buy | Estimate: controller about $22 and logic board about $18; firmware is a labeled sketch only
13 Display level selector lanyard stop and key switch | 1 | Handlebar LCD for speed level and pack charge; three-position level selector; key switch in the INTERLOCK loop; magnetic lanyard stop switch with wrist or belt clip; each on its own bar clamp | E-bike parts supplier and electronics distributor | 24.00 | buy | Estimate
14 Guards | 1 | Heel guard 1.5 mm aluminium with a bottom flange on the rear cross member; two roller covers 1 mm aluminium on the rail inside faces; toe guard 2 mm aluminium leaning back 20 degrees on the nose beam; two 6 mm HDPE side boards 1.06 m x 70 mm on eight 13 mm spacers; bought 20 in rear fender 60 mm wide with two stays to the dropouts | Local sheet-metal or plastics supplier; bicycle shop | 42.00 | make | Estimate (SGN-DDR-003); about 0.4 m2 of sheet plus the fender
15 Wiring harness with fuse | 1 | Waterproof keyed connectors, 20 A blade fuse in a sealed holder, sensor and motor cables run inside the left deck rail between two grommets, spiral wrap, cable ties | E-bike parts supplier | 17.00 | buy | Estimate
16 Hardware kickstand and consumables | 1 | Side kickstand bolted to the welded plate on the left rail; bolts, nuts, washers, M6 rivet nuts, welding wire, paint, cable ties, grease | Hardware store and bicycle shop | 42.00 | buy | Estimate; no exploded-view callout for the hardware

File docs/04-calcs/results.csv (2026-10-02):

id | value | target | status
R1 | Usable belt 1.00 m x 0.40 m; push 22 to 30 N at 5 km/h; 1.00 m fits a 1.75 m rider only up to 5 km/h | 1.0 m, 0.36 m, 30 N at 5 km/h | At risk
R2 | Belt-stop to motor-off 261 ms; brake and lanyard about 30 ms; start after 11 pulses in 0.5 s | Start after 0.5 s above 1.5 km/h; off within 0.5 s | Met (on paper)
R3 | Cut at 25 km/h, beginner 15 km/h; torque limit 32 N m gives 1.0 m/s2 | 25 km/h, 15 km/h mode, 1.0 m/s2 or less | Met (on paper)
R4 | 250 W rated motor specified; wheel power capped at 250 W | 250 W rated or less | Met (on paper)
R5 | 45 km at 20 km/h on the flat (9.1 Wh/km); about 32 km in real use | 30 km at 20 km/h | Met
R6 | 235 W at the wheel for 8 % at 8 km/h (6 % margin) | 8 % at 8 km/h within 250 W | At risk
R7 | 8.0 m at 3 m/s2; rear brake alone 9.6 m; belt held by the one-way bearing with 500 N tension | Two brakes; 10 m from 25 km/h; belt cannot run forward | Met (on paper)
R8 | Belt top 240 mm; side boards 9 mm proud of the belt, no rails | 250 mm or less; open sides | Met
R9 | Guards modelled at both nips, rear tire and belt ends; gaps not yet checked against ISO 13857 | Nips, spokes and rear tire guarded | Not verifiable at TRL 3
R10 | 2.38 m long, 0.58 m wide, 37.9 kg with pack (2.1 kg margin, less than a 10 % growth allowance) | 2.4 m, 0.65 m, 40 kg | At risk
R11 | Interface v0.3: 10 kOhm coded INTERLOCK (node 0.30 V), vehicle heartbeat mode 2; 8.5 A maximum; below 60 V | SwapCell v0.3 unchanged; 15 A or less; below 60 V DC | Met (on paper)
R12 | Reference (salvage) build $610 excluding the pack, $40 under the value-engineering target; all-new-parts fallback $750 | $650 value-engineering target excluding the pack on the reference build | Under the target (on paper)
R13 | Class V1 receiver specified: preload 330 N, lever ratio 6.6, bolts factor 22 at 25 g | SwapCell latch class V1, no release or contact break | Not verifiable at TRL 3

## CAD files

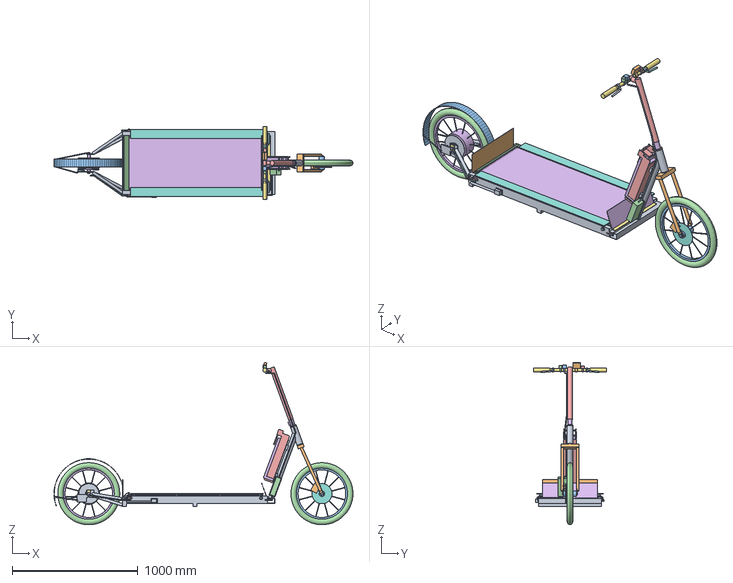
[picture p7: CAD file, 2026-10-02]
cad/step/stepgen-assembly.step
2379.0 x 580.0 x 1292.4 mm

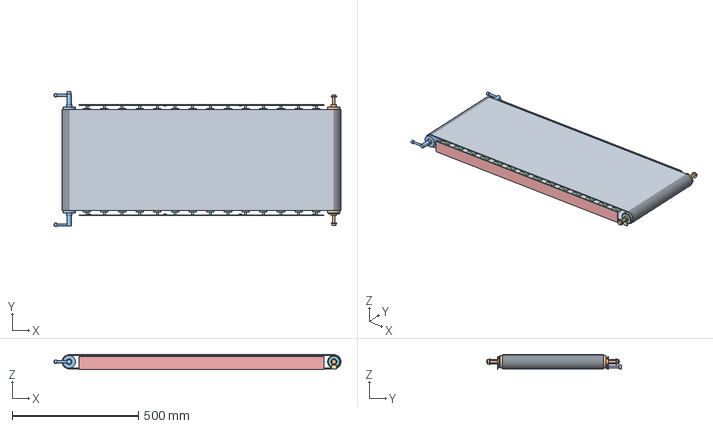
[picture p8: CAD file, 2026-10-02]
cad/step/stepgen-deck.step
1138.0 x 535.5 x 58.0 mm

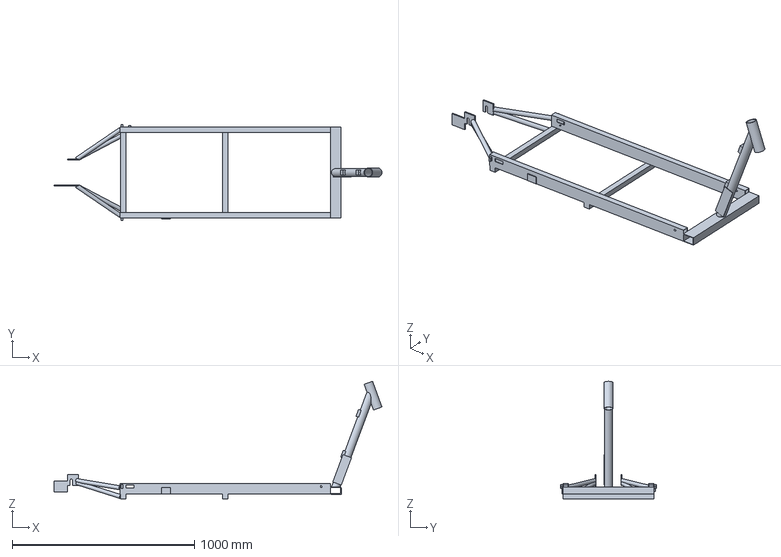
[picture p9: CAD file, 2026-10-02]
cad/step/stepgen-frame.step
1798.5 x 526.0 x 644.5 mm

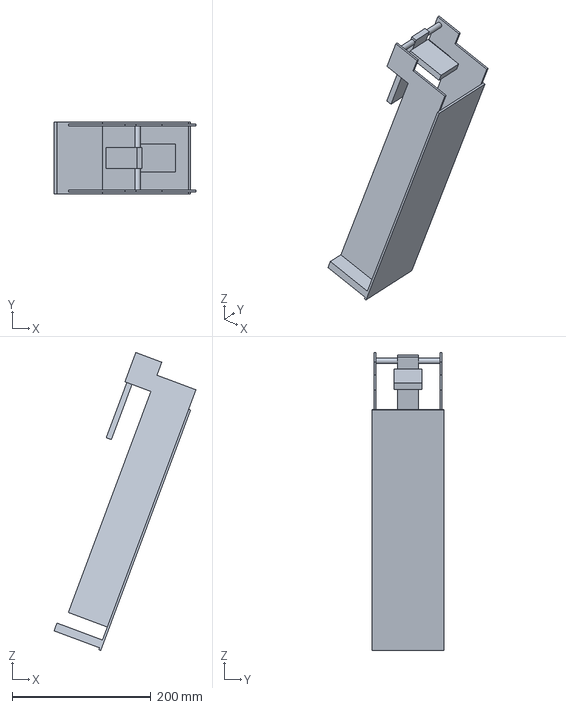
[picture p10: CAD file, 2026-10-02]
cad/step/stepgen-receiver.step
204.5 x 104.0 x 429.5 mm

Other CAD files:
cad/stl/stepgen-assembly.stl
cad/stl/stepgen-deck.stl
cad/stl/stepgen-frame.stl
cad/stl/stepgen-receiver.stl

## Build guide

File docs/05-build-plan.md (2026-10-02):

---
doc_id: SGN-BLD-001
title: StepGen prototype build plan
project: StepGen
doc_type: Build plan
version: "0.2"
status: Draft
date: '2026-10-02'
author: Amish Chadha
license: CERN-OHL-S-2.0
revisions:
  - version: "0.1"
    date: '2026-10-01'
    author: Amish Chadha
    change: First build plan, with pictures by component and step; design made constructable (SGN-DDR-003)
  - version: "0.2"
    date: '2026-10-02'
    author: Amish Chadha
    change: 'Safety stop S7: legal category confirmed with the RDW before road use (decided by Amish, 2026-10-02)'
---

# StepGen prototype build plan

**Plan, not yet built.** How to build the first proof-of-concept prototype, component by component. Building and testing to it is TRL 4 work. Decisions still to be made are kept in the design decisions register ([docs/06-design-decisions.md](06-design-decisions.md)), not here.

## 1. What you are building

Figure 1. Every component, pulled apart and numbered in build order

*Figure 1. Every component pulled apart and numbered in build order; the SwapCell pack (22) goes in last, after the safety stops.*

The prototype is one StepGen walking vehicle: a welded steel frame carrying a free-running treadmill belt between two 20 in wheels, a 250 W hub motor in the rear wheel, a steering column with a handlebar at 1.23 m, and a SwapCell pack in a cradle on the down tube. Figure 1 shows the 22 components in the order you make or fit them. Nine are made in a workshop with a welder: the frame (from rails, cross members, a nose beam, a down tube, stays, dropouts and small plates), the two idler carrier bars, the sensor bracket, the steering column, the receiver cradle, the heel guard, the two roller covers, the toe guard and the two side boards. The rest are bought and fitted: belt and rollers (from a used walking-pad treadmill), idler rollers, fork, wheels, hub motor, brakes, controller, logic board, controls, harness, kickstand and fender. The work is sawing, drilling and welding steel tube and plate, folding aluminium sheet, cutting plastic sheet, and bolting and wiring bought parts. The parts cost about USD 610 on the salvage route, pack excluded, from the bill of materials.

> **Safety:** StepGen carries a 468 Wh lithium-ion pack at up to 54.6 V DC and has a moving belt that a person stands on. Keep the pack out of the cradle and the fuse out until section 6 says otherwise. Welding needs a proper welding screen, gloves and ventilation; galvanised or painted steel must be ground clean before welding. Cut steel and aluminium edges are sharp: deburr everything.

## 2. What changed to make it buildable

The concept showed what StepGen does; many of its parts could not be made or fixed as drawn. Each change below keeps what the vehicle does, and all of them are recorded in decision record SGN-DDR-003, open for Amish's review.

*Table 1. Changes from the concept.*

| Component | The concept had | The buildable design has | Why |
| --- | --- | --- | --- |
| Rear stays | Upper stays running through the rear roller and the belt | An upper stay from each rail's end cap and a lower stay from the rear cross member, both to the dropout (Figures 7 and 10) | The stays stay behind the deck and form a stiff triangle |
| Brakes | Rotors outside the dropouts and fork legs, calipers with no mount | Rotors on the hubs inside the dropouts; rear caliper on a tab on the left dropout, front caliper on the fork's post mount (Figures 9 and 28) | Standard disc positions for these hubs |
| Head tube and fork | A plain 44 mm tube; fork legs overlapping the hub | A bought head tube machined for a ZS44 headset; a 26 in size rigid fork carrying the 20 in wheel (Figure 19) | A headset needs a machined bore; the head tube sits higher than a 20 in fork reaches |
| Down tube | Joined at the bottom of the head tube, where the fork crown hit it | Joined 100 mm higher, on the side of the head tube (Figure 19) | The fork turns 45 degrees each way with room to spare |
| Front of the deck | Two nose tubes and a block | One nose beam across the rail ends; the down tube stands on it (Figure 6) | Flat faces for the down tube, the toe guard and the harness |
| Cross members | Cut into the rails, not fixed | Welded under the rails (Figure 4) | Full weld faces; clear of the belt |
| End rollers | Axles with no fixing; tensioner and anti-reverse clutch outside the rail with no mount | Fixed axles bolted to the rails; rear axle in slots with tension bolts; a one-way bearing inside the rear roller; a felt-tipped drag screw (Figures 10, 15 and 16) | Keeps a salvaged treadmill roller usable; nothing sticks out |
| Speed sensor | A magnet ring outside the rail on an axle that does not turn | A magnet ring on the front roller's end, read by a sensor on a bracket inside the rail (Figure 15) | The roller turns; its axle does not |
| Roller bed | Rollers running into floating carriers | Carrier bars screwed to the rails' inside walls; the rollers' spring axles clip into them (Figure 13) | Uses the rollers' standard axles |
| Guards and side boards | Floating plates | Each with a flange or tab screwed to the frame; side boards on spacers (Figures 23 to 27) | Every guard is fixed |
| Receiver cradle | A solid block; the lever stood where the pack's handle is | A folded channel on two tabs with an end stop and an over-centre lever beside the handle (Figures 21 and 22) | Same preload and fit, and it can be made |
| Controller | Under the down tube, in the front tire's path | On a plate on the left of the down tube (Figure 6) | Clear of the wheel at full lock |
| Steering column and bar | No joint to the fork; grip bends and controls overlapping | A welded column that clamps the steerer; a straight 580 mm bar with each control on its own clamp (Figures 19 and 20) | Stock tube sizes slide into each other; no lathe needed |
| Kickstand and wiring | No mount; harness through the frame | Kickstand on a welded plate; harness inside the left rail (Figures 6 and 11) | Each has a place to sit, away from the belt and wheels |

The vehicle is now 2.38 m long including the rear fender, 0.58 m wide and 35.1 kg without the pack. Wheelbase, steering geometry, belt length and height, and bar height are unchanged.

## 3. Making the components

Make and check each component before the assembly step that needs it. Sizes are in millimetres. "Left" and "right" are as seen by the rider standing on the belt, facing forward. "Rear end" of a rail is the end nearer the rear wheel. Workshop tolerance is 1 mm unless a step says otherwise; drawings do not carry tolerances before TRL 4.

### 3.1 Main frame

The frame is welded from seven kinds of piece, made first (sections 3.1.1 to 3.1.6) and then welded up in a jig (section 3.1.7). Mild steel, S235 class, throughout.

#### 3.1.1 Deck rails (make 2, a right and a left)

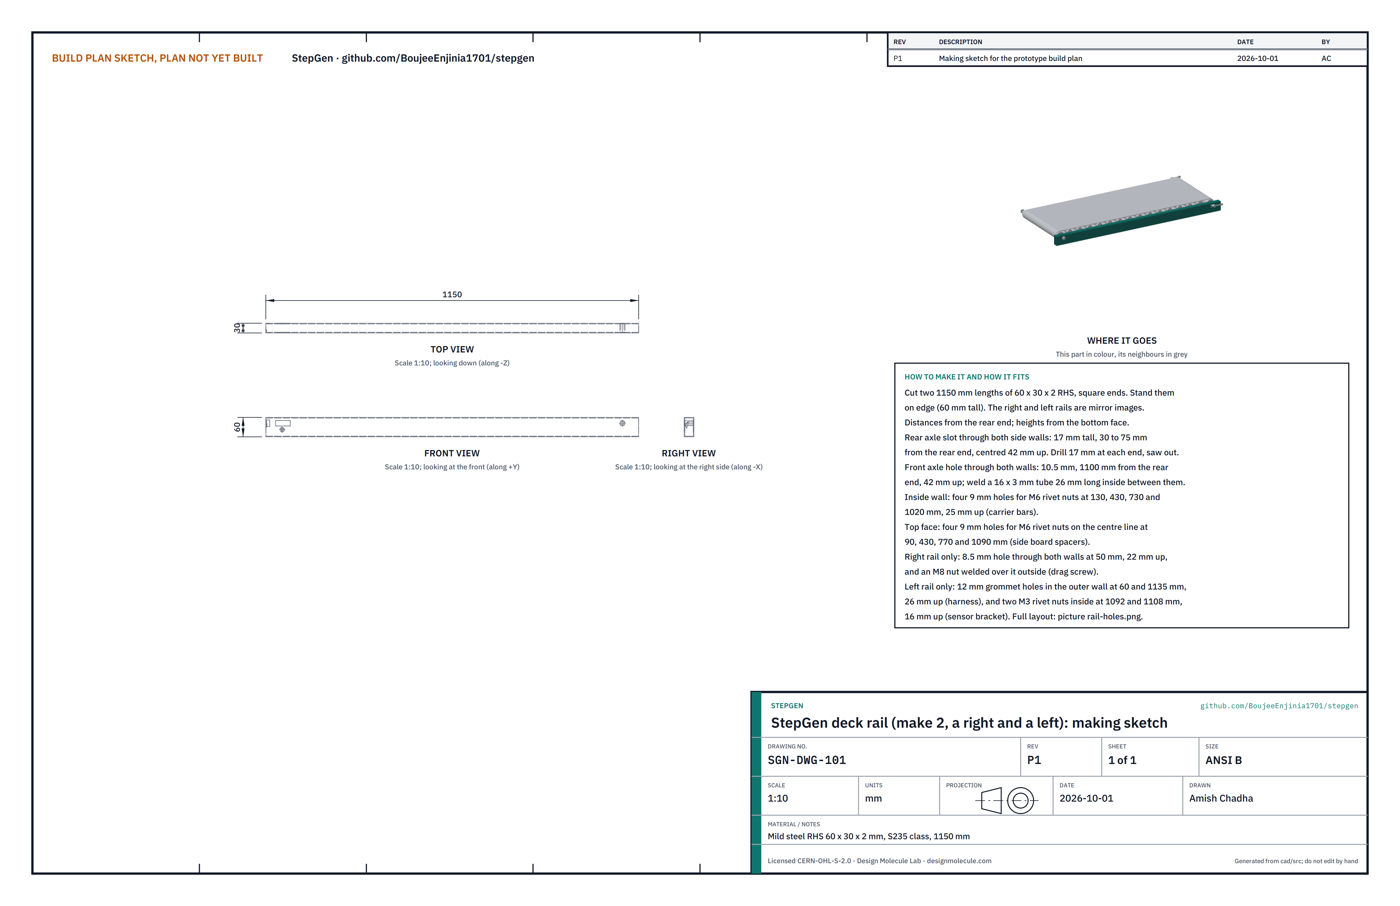
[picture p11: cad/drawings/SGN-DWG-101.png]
Figure 2. Making sketch of the deck rail


*Figure 2. Deck rail making sketch (SGN-DWG-101).*

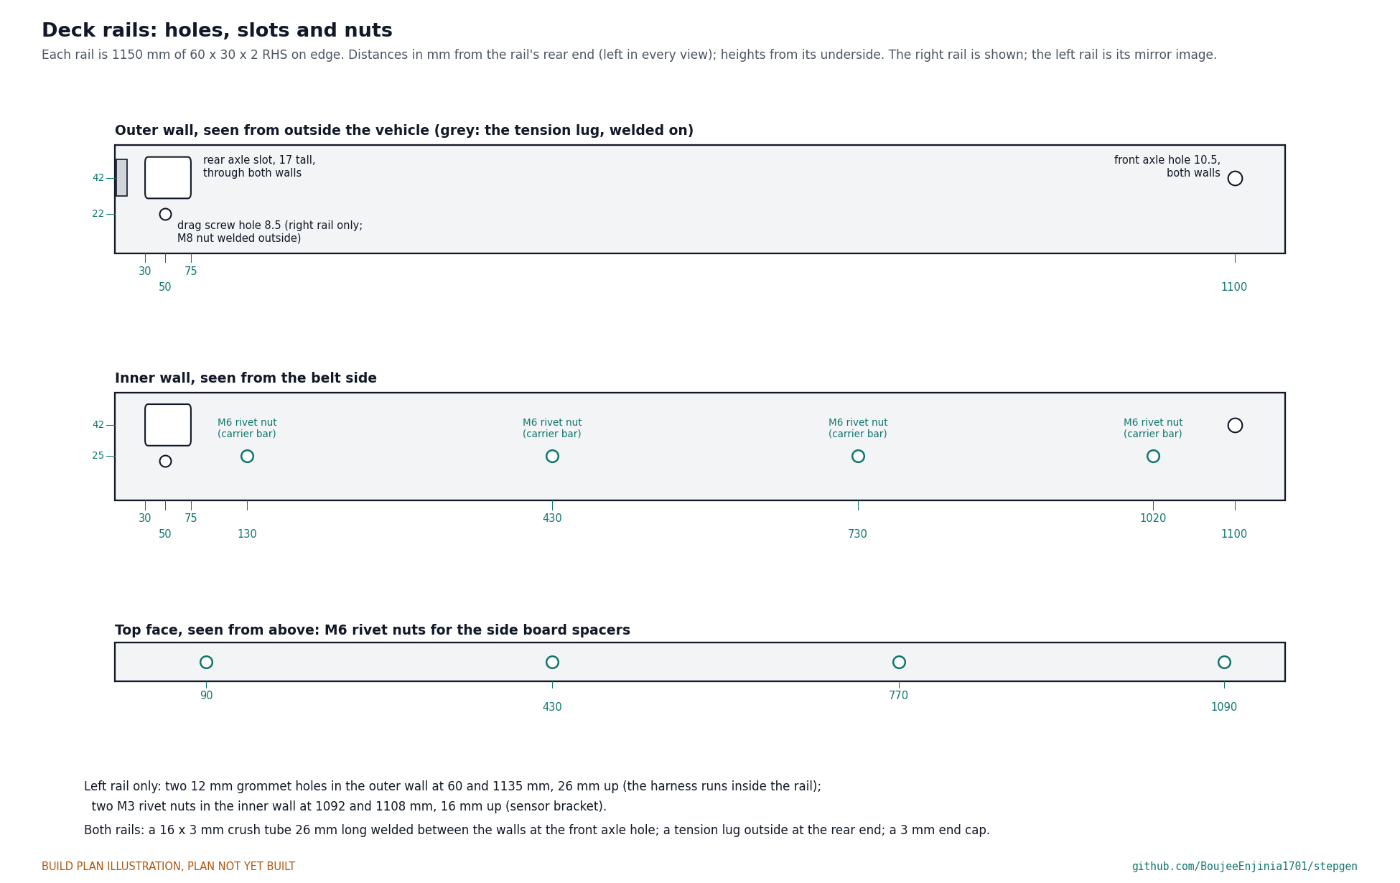
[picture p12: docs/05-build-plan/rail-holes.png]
Figure 3. Hole and slot positions in the deck rails


*Figure 3. Every hole, slot and nut in the rails, measured from the rear end and up from the underside.*

**What it is and what it is made from.** The two long side members that carry the belt, the rollers and the rider. 60 x 30 x 2 mm rectangular hollow section, standing on edge, 1150 mm long.

**How to make it.**

1. Cut two 1150 mm lengths, square. Mark one face of each as the outer wall; the right and left rails are mirror images, so mark them as a pair.
2. Rear axle slot, through both side walls: 17 mm tall, from 30 to 75 mm from the rear end, centred 42 mm up. Drill 17 mm at each end and saw out between; file straight.
3. Front axle hole, through both side walls: 10.5 mm, 1100 mm from the rear end, 42 mm up. Slide a 26 mm length of 16 x 3 mm tube inside between the walls on a 10 mm bolt and weld it in through the hole edges (the crush tube).
4. Inside wall: four 9 mm holes at 130, 430, 730 and 1020 mm, 25 mm up, and fit M6 rivet nuts (carrier bars).
5. Top face: four 9 mm holes on the centre line at 90, 430, 770 and 1090 mm, and fit M6 rivet nuts (side board spacers).
6. Right rail only: an 8.5 mm hole through both walls at 50 mm, 22 mm up; weld an M8 nut over it on the outside (drag screw).
7. Left rail only: 12 mm holes in the outer wall at 60 and 1135 mm, 26 mm up, for grommets (the harness runs inside); two M3 rivet nuts in the inside wall at 1092 and 1108 mm, 16 mm up (sensor bracket).
8. Deburr every hole inside and out.

**How it fits the parts next to it.** The rails stand on edge, 440 mm apart inside, with the cross members welded under them and the nose beam across their front ends (section 3.1.7).

**Check before moving on.** Lay the two rails side by side, outer walls out: every hole and slot pair lines up.

#### 3.1.2 Cross members and nose beam

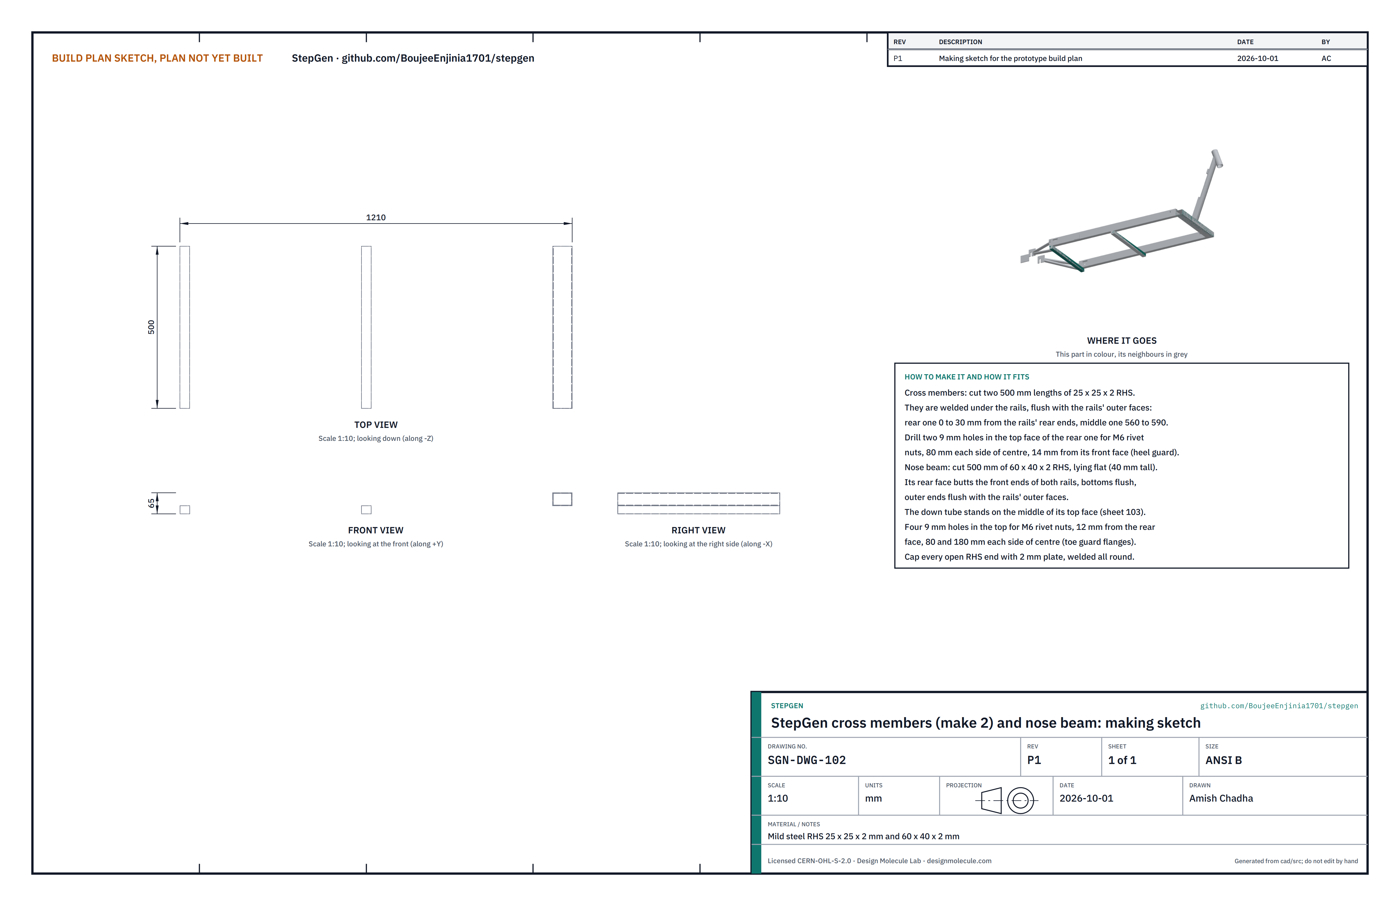
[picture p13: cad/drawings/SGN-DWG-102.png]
Figure 4. Making sketch of the cross members and nose beam


*Figure 4. Cross members and nose beam making sketch (SGN-DWG-102).*

**What they are and what they are made from.** Two cross members tie the rails together from underneath; the nose beam ties their front ends and carries the down tube. 25 x 25 x 2 mm and 60 x 40 x 2 mm rectangular hollow section.

**How to make them.**

1. Cut two 500 mm lengths of 25 x 25 x 2 mm and one 500 mm length of 60 x 40 x 2 mm.
2. Rear cross member: two 9 mm holes in its top face, 80 mm each side of centre, 14 mm from its front face; fit M6 rivet nuts (heel guard).
3. Nose beam, lying flat (40 mm tall): four 9 mm holes in its top, 12 mm from its rear face, 80 and 180 mm each side of centre; fit M6 rivet nuts (toe guard).
4. Cap every open end with 2 mm plate, welded all round.

**How they fit the parts next to them.** The cross members sit under the rails, flush with the rails' outer faces: the rear one from 0 to 30 mm from the rails' rear ends, the middle one from 560 to 590 mm. The nose beam's rear face butts both rails' front ends, its underside flush with theirs.

**Check before moving on.** Each piece is 500 mm long within 1 mm and its ends are square.

#### 3.1.3 Down tube

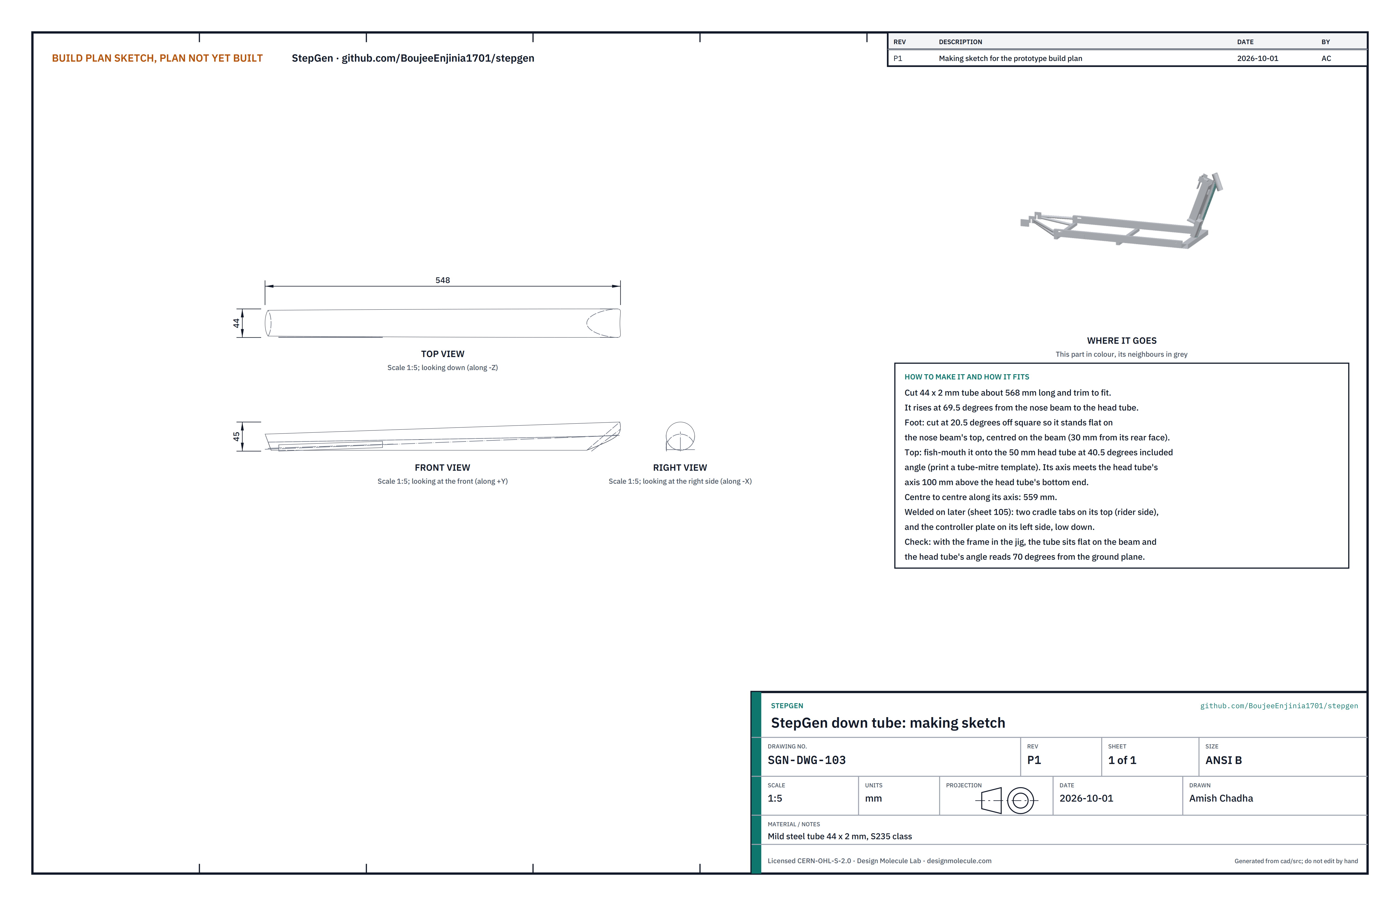
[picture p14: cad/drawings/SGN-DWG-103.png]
Figure 5. Making sketch of the down tube


*Figure 5. Down tube making sketch (SGN-DWG-103), drawn laid flat along its axis.*

**What it is and what it is made from.** The tube from the nose beam up to the head tube, which carries the pack cradle and the controller. 44 x 2 mm steel tube.

**How to make it.**

1. Cut about 568 mm and trim to fit in the jig.
2. Foot: cut 20.5 degrees off square, so the tube stands at 69.5 degrees on the nose beam's flat top, centred on the beam.
3. Top: fish-mouth it to the 50 mm head tube at a 40.5 degree included angle. Print a tube mitre template for 44 mm onto 50 mm and file to it.

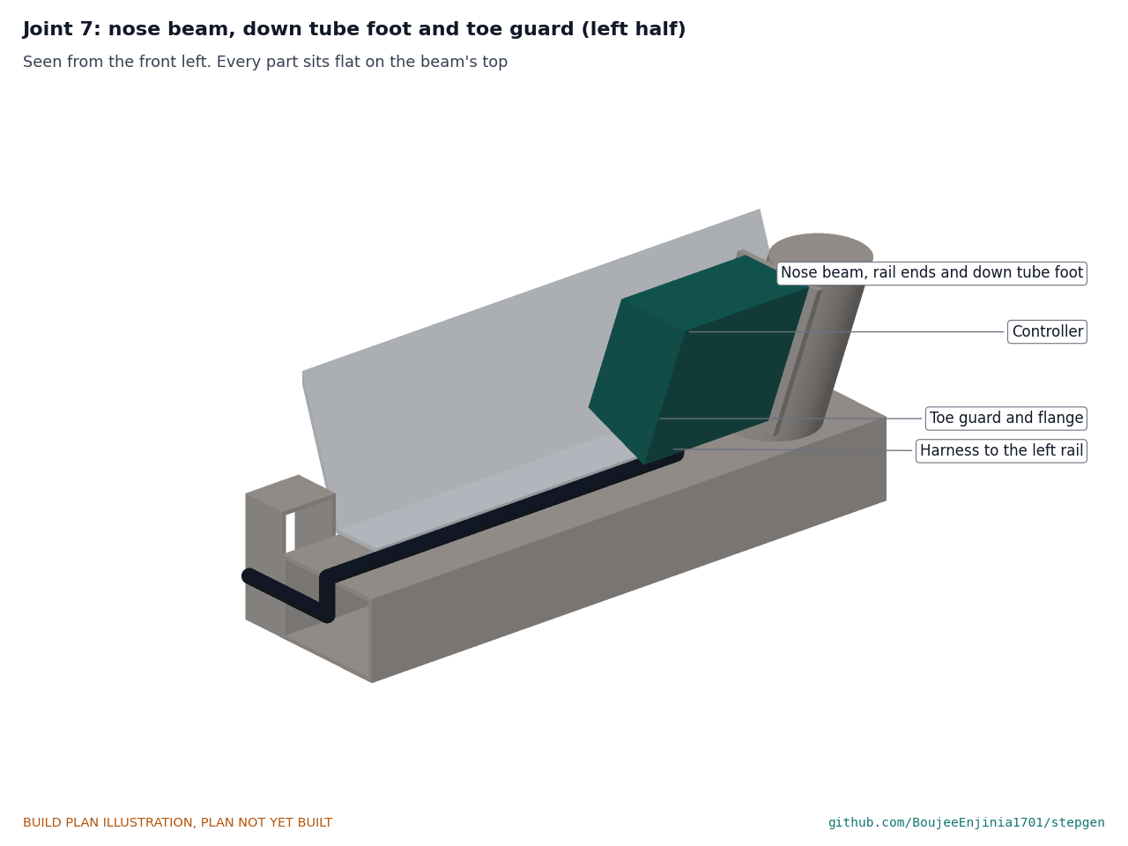
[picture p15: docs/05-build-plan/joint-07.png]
Figure 6. Joint 7: nose beam, down tube foot and toe guard


*Figure 6. Left half of the nose: the down tube stands on the nose beam; the toe guard's flange and the harness lie on its top; the controller sits on its plate on the down tube.*

**How it fits the parts next to it.** Its foot stands on the middle of the nose beam's top; its axis meets the head tube's axis 100 mm above the head tube's bottom end, 559 mm from the foot (Figure 6 and Figure 19).

**Check before moving on.** In the jig the foot sits flat on the beam and the fish-mouth closes on the head tube with no gap over 1 mm.

#### 3.1.4 Rear stays and dropouts

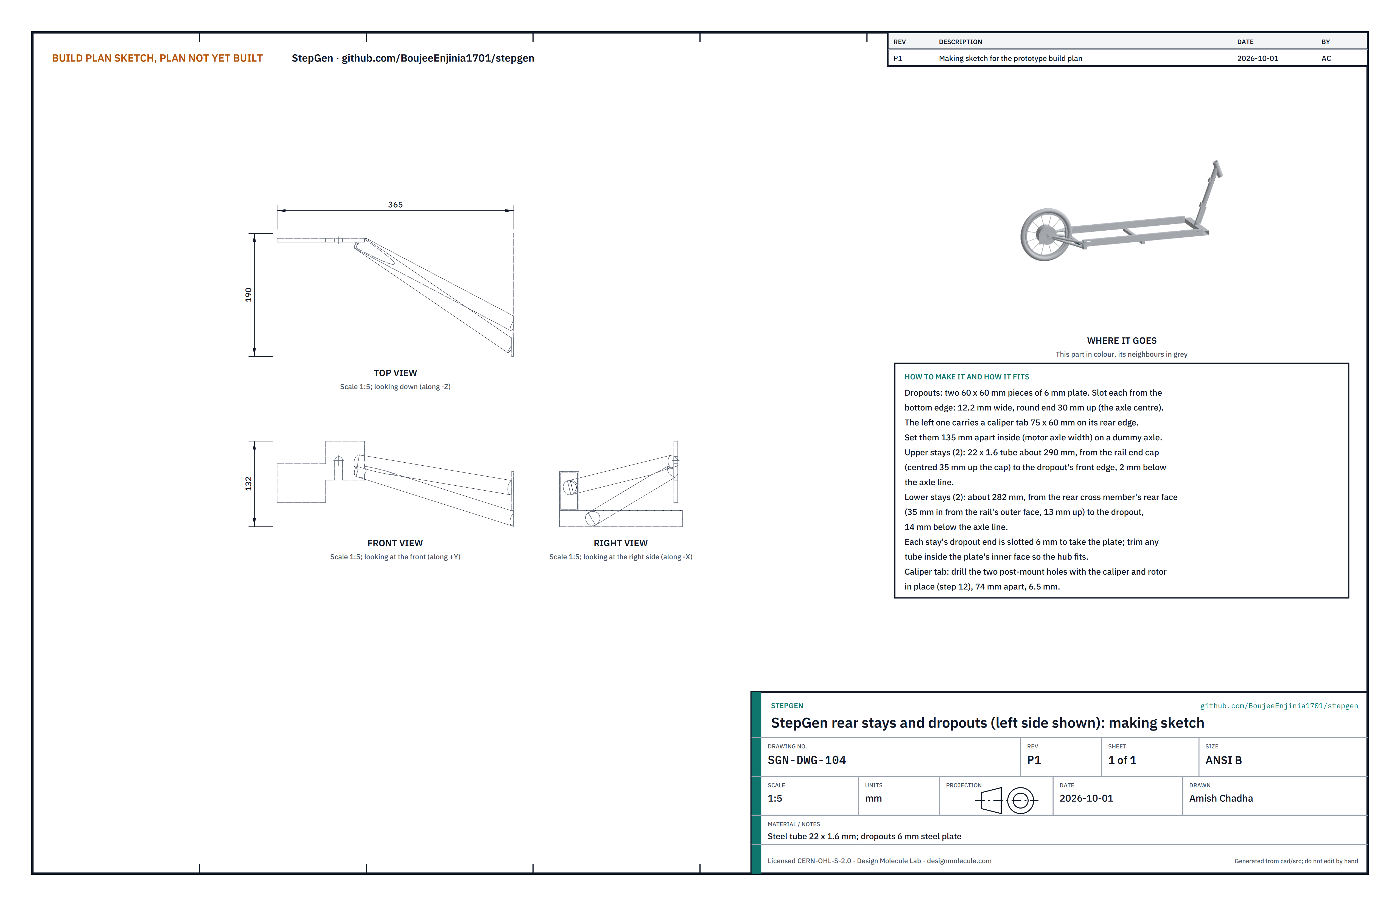
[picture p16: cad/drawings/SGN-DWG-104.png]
Figure 7. Making sketch of the rear stays and dropouts


*Figure 7. Rear stays and dropouts making sketch (SGN-DWG-104), left side.*

**What they are and what they are made from.** The rear triangle on each side that holds the hub motor: an upper and a lower stay of 22 x 1.6 mm tube and a 6 mm steel dropout plate. The left dropout carries the rear caliper tab.

**How to make them.**

1. Dropouts: cut two 60 x 60 mm squares of 6 mm plate; on the left one, leave a 75 x 60 mm tab on its rear edge. Slot each from its bottom edge: 12.2 mm wide, round end 30 mm up (the axle centre).
2. Upper stays: two lengths of about 290 mm. Lower stays: two of about 282 mm. Cut them long.
3. Slot each stay's dropout end 6 mm wide and 20 mm deep to take the plate.
4. Trim the stays to fit in the jig (section 3.1.7): each upper stay lands on the rail's end cap, centred 35 mm up; each lower stay lands on the rear cross member's rear face, 35 mm in from the rail's outer face and 13 mm up.

**How they fit the parts next to them.**

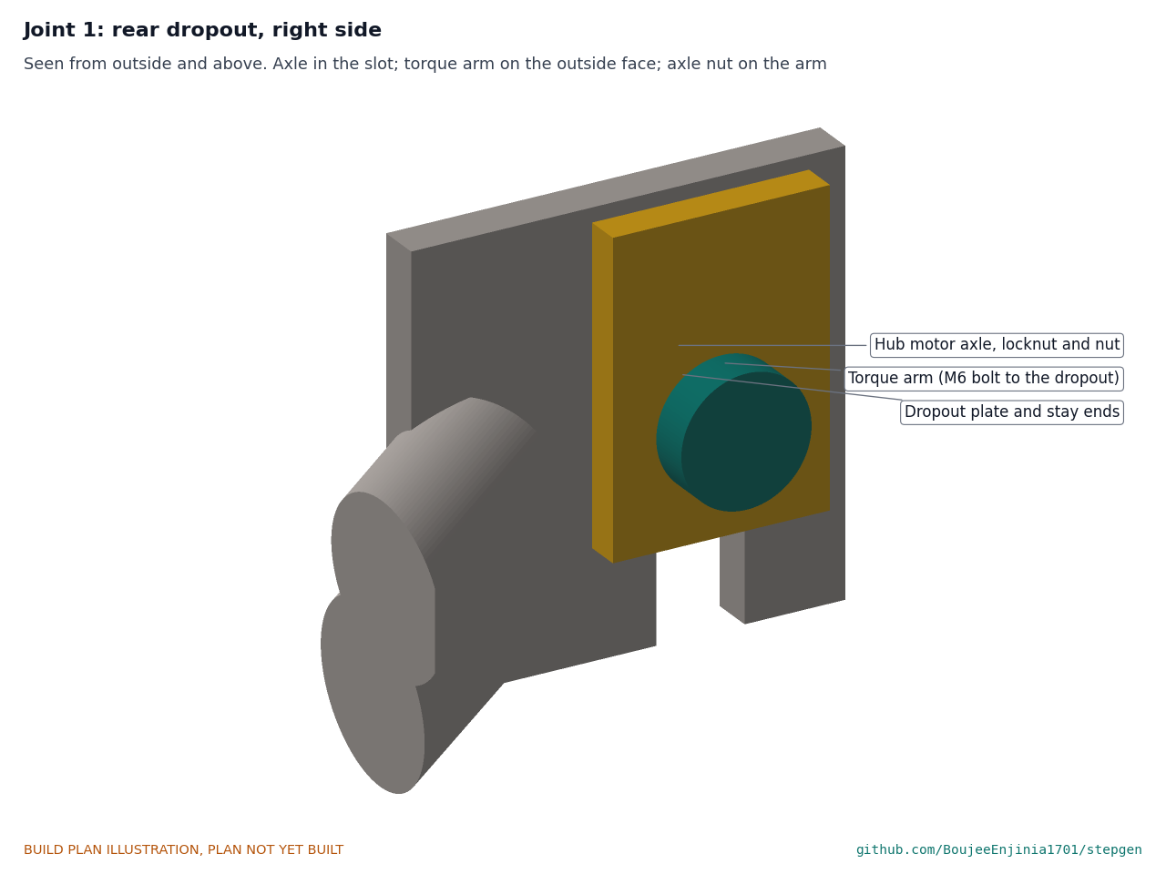
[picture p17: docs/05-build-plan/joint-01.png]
Figure 8. Joint 1: the rear dropout, right side


*Figure 8. The motor's axle sits in the dropout's slot; a torque arm bolts to the outside of the dropout and the axle nut tightens onto it.*

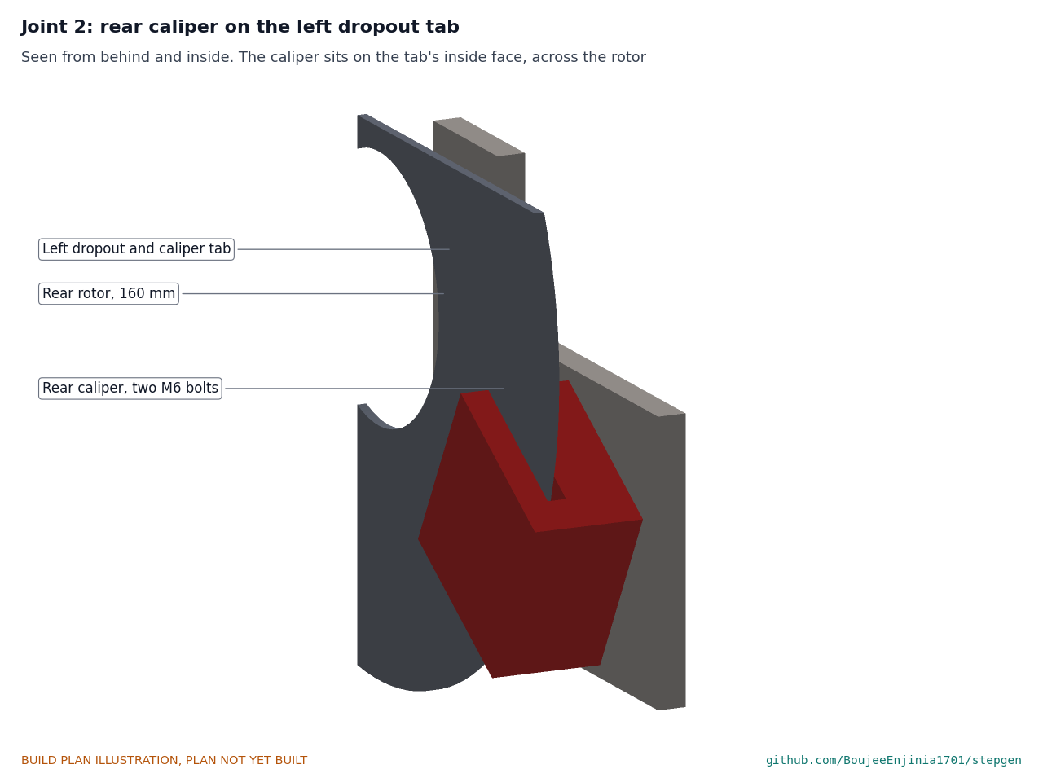
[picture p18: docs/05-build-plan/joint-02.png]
Figure 9. Joint 2: rear caliper on the left dropout tab


*Figure 9. The rear caliper bolts to the inside face of the left dropout's tab, straddling the rotor.*

The dropouts sit 135 mm apart inside, the motor axle's width. Any stay tube that reaches inside a dropout's inner face is ground away so the hub fits. The caliper tab's two holes are drilled with the caliper and rotor in place (step 12).

**Check before moving on.** On a 135 mm dummy axle, the two slots line up and the plates are parallel.

#### 3.1.5 Small welded parts

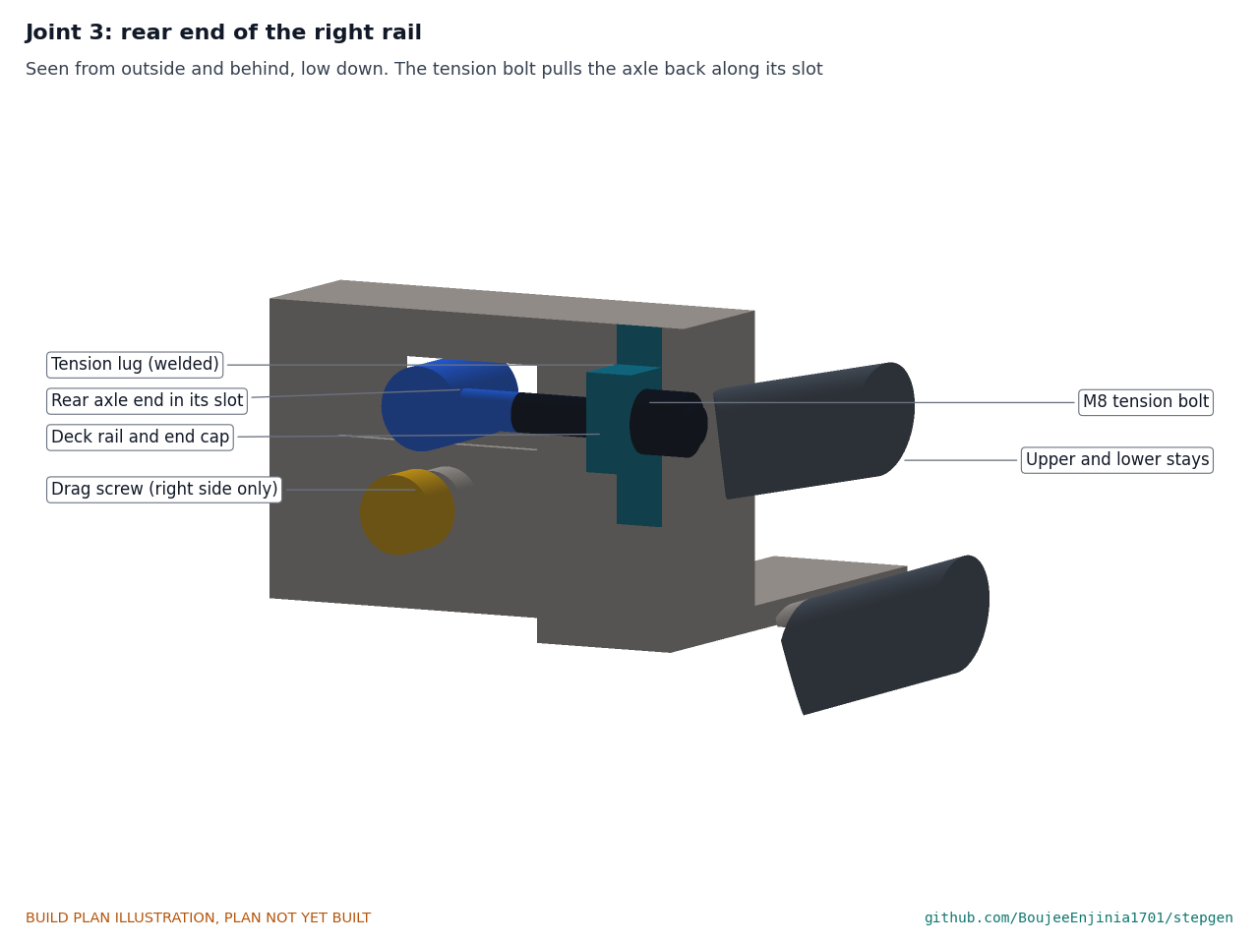
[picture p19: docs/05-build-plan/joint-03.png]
Figure 10. Joint 3: rear end of the right rail


*Figure 10. The rail's end cap carries the upper stay; the tension lug beside it carries the bolt that pulls the rear roller's axle back along its slot. The drag screw is on this rail only.*

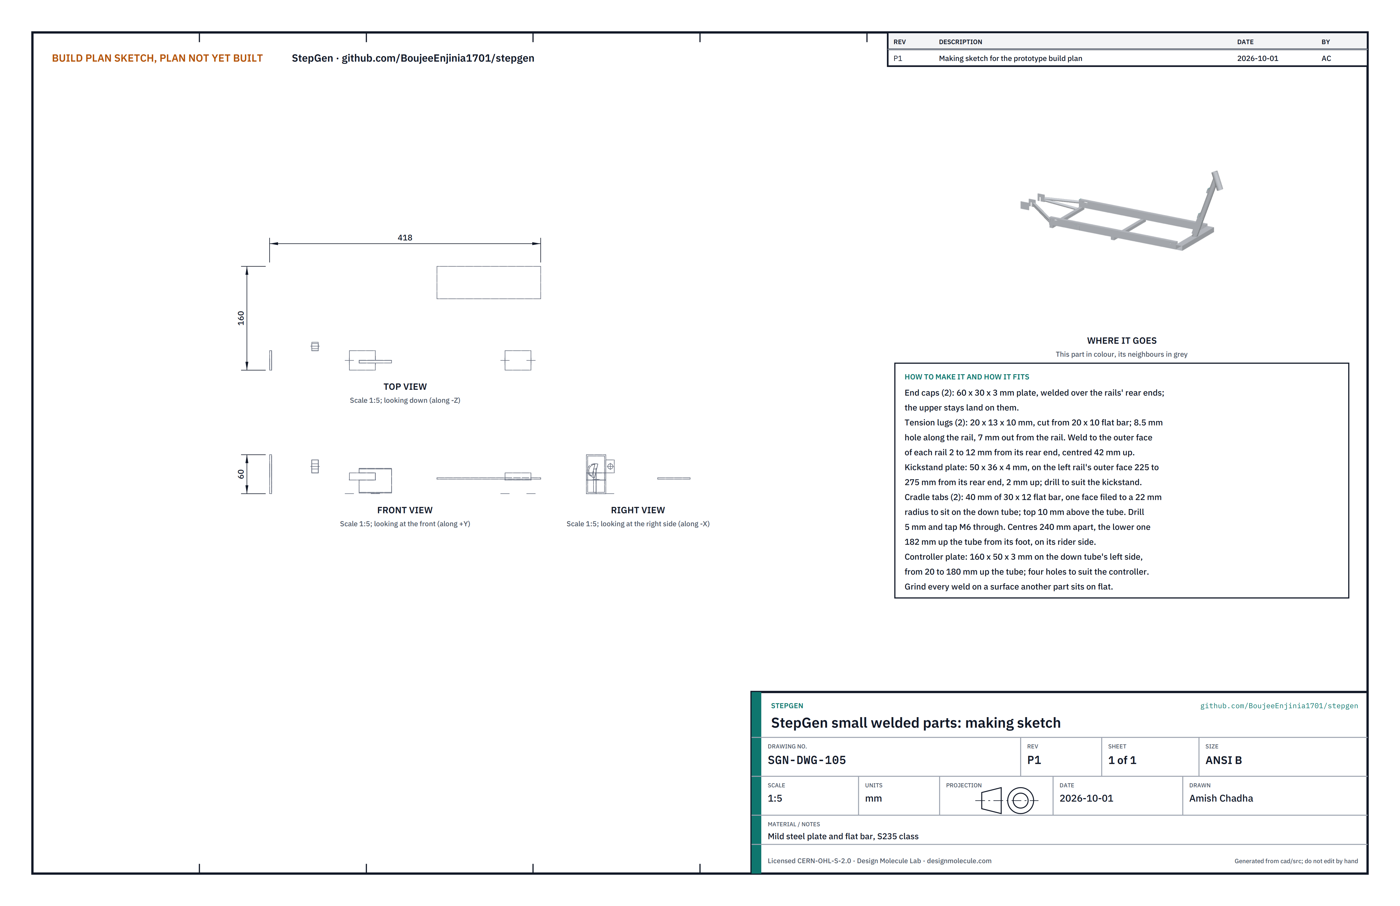
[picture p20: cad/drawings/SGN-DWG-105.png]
Figure 11. Making sketch of the small welded parts


*Figure 11. End cap, tension lug, kickstand plate, cradle tabs and controller plate (SGN-DWG-105).*

**What they are and what they are made from.** Mild steel plate and flat bar:

- End caps (2): 60 x 30 x 3 mm, over the rails' rear ends.
- Tension lugs (2): 20 x 13 x 10 mm from 20 x 10 mm flat bar, with an 8.5 mm hole along the rail, 7 mm out from the rail; on each rail's outer wall, 2 to 12 mm from the rear end, centred 42 mm up.
- Kickstand plate: 50 x 36 x 4 mm, on the left rail's outer wall, 225 to 275 mm from the rear end, 2 mm up; drilled to suit the kickstand bought.
- Cradle tabs (2): 40 mm lengths of 30 x 12 mm flat bar, one face filed to a 22 mm radius to sit on the down tube, the top face 10 mm above the tube; drilled 5 mm and tapped M6. On the down tube's rider side, 240 mm apart, the lower one 182 mm up the tube from its foot.
- Controller plate: 160 x 50 x 3 mm, on the left side of the down tube from 20 to 180 mm up the tube, with four holes to suit the controller bought.

**How to make them.** Saw, file and drill each from the sizes above. Grind every weld on a face that another part sits on.

**Check before moving on.** Each lug's hole lines up with the rail's slot centre (42 mm up).

#### 3.1.6 Head tube

A bought steel head tube, 50 x 3 mm and 150 mm long, machined at both ends for a ZS44 semi-integrated headset (cups pressed into the tube). It is welded in as it comes.

#### 3.1.7 Welding up the frame

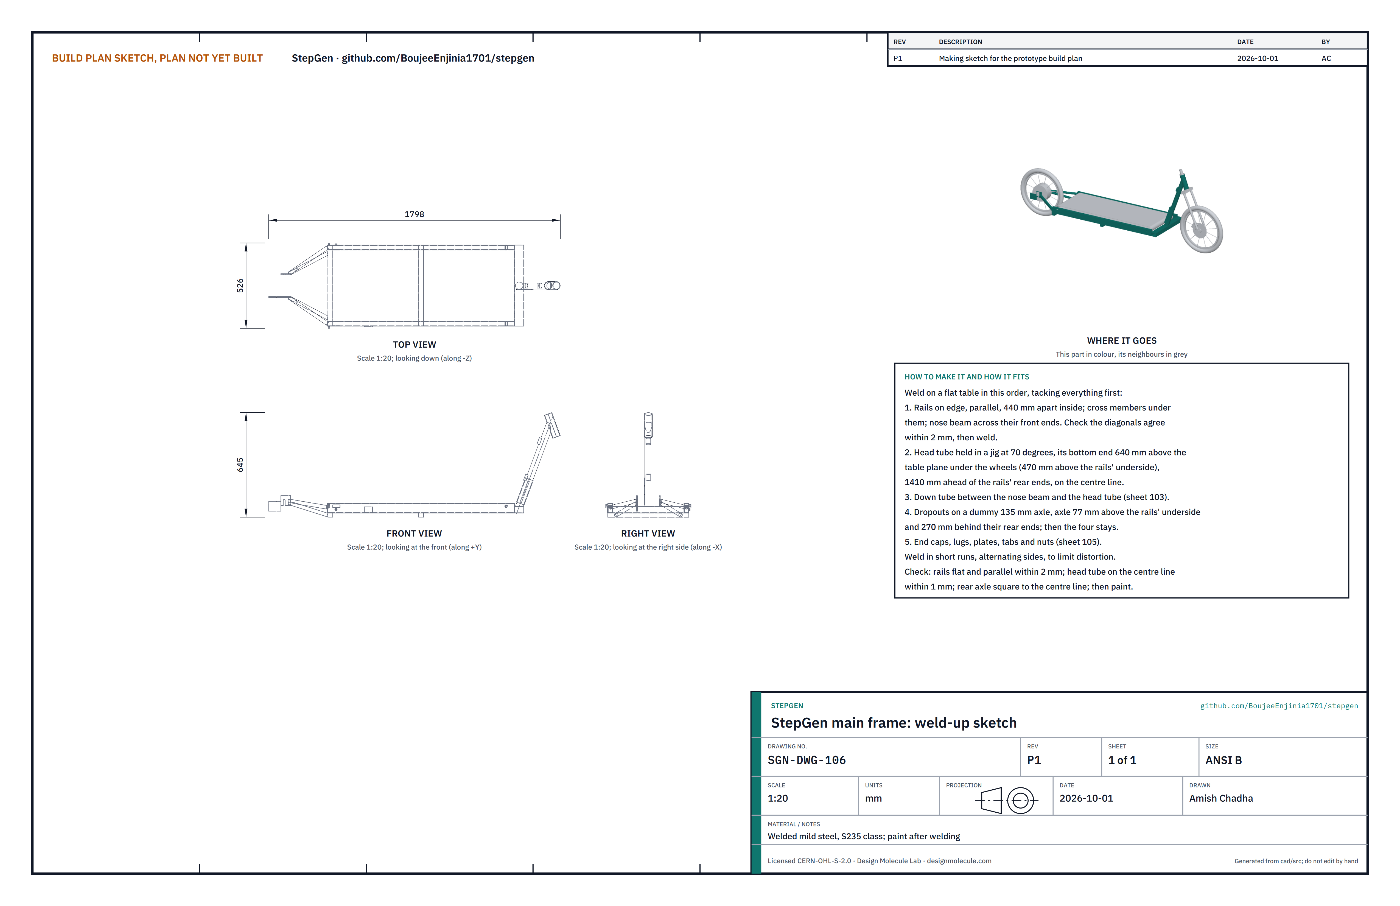
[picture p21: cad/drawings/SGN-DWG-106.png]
Figure 12. Weld-up sketch of the main frame


*Figure 12. Main frame weld-up sketch (SGN-DWG-106).*

**How to make it.** Weld on a flat table, tacking everything first and welding in short runs, alternating sides, to limit distortion.

1. Set the rails on edge, parallel, 440 mm apart inside, outer walls out. Tack the cross members under them and the nose beam across their front ends. Check the diagonals agree within 2 mm, then weld.
2. Hold the head tube in a jig at 70 degrees from the ground plane, on the centre line, its bottom end 1410 mm ahead of the rails' rear ends and 470 mm above the rails' underside (640 mm above the ground).
3. Fit and weld the down tube between the nose beam and the head tube.
4. Set the dropouts on a 135 mm dummy axle, 270 mm behind the rails' rear ends and 77 mm above the rails' underside, square to the centre line. Fit and weld the four stays.
5. Weld on the end caps, tension lugs, kickstand plate, cradle tabs, controller plate and the drag screw nut.
6. Clean, prime and paint; keep paint off the head tube's bores and the faces where the dropouts meet the hub.

**Check before moving on.** Rails flat and parallel within 2 mm; head tube on the centre line within 1 mm; the dummy axle square to the centre line within 1 mm over its length.

### 3.2 Idler carrier bars (make 2)

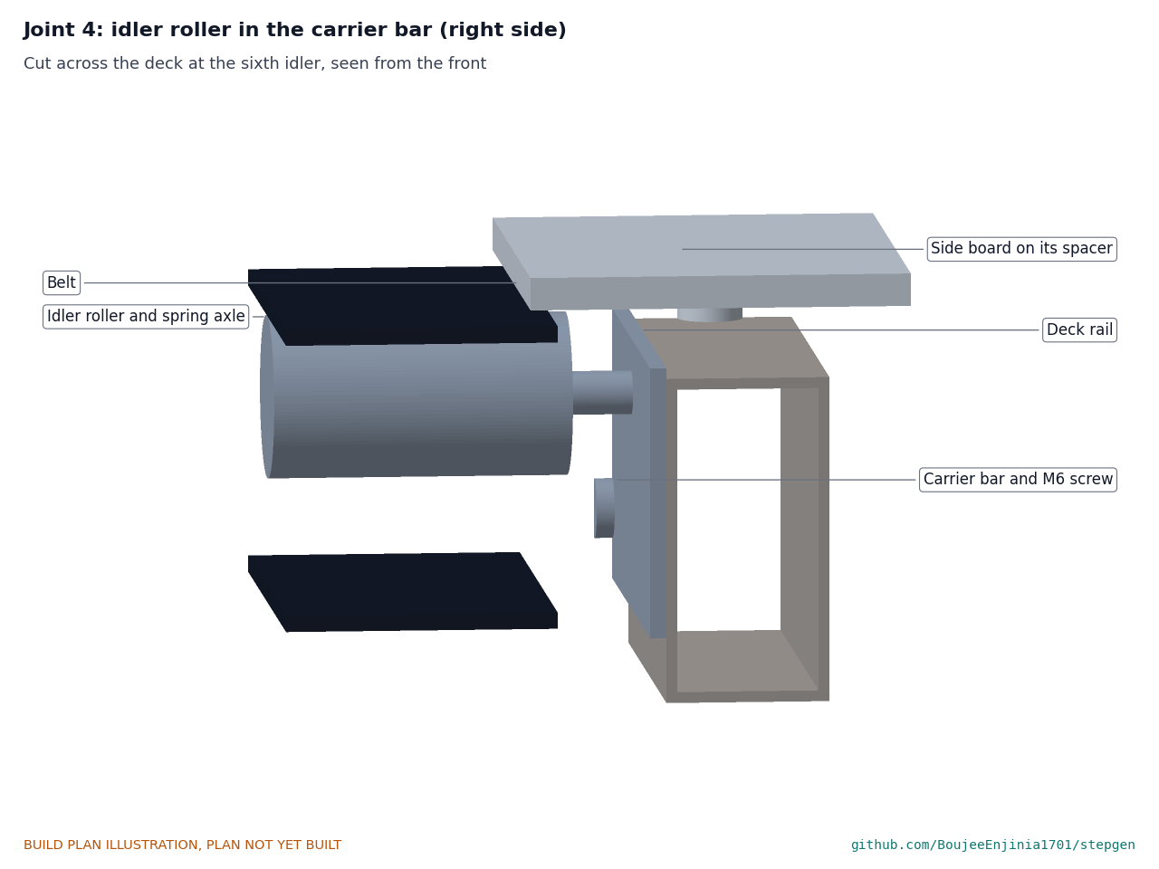
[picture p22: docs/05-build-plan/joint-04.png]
Figure 13. Joint 4: idler roller in the carrier bar


*Figure 13. Cut across the deck: the idler's spring axle clips into the carrier bar, which is screwed to the rail; the belt runs on the idler; the side board sits on its spacer above.*

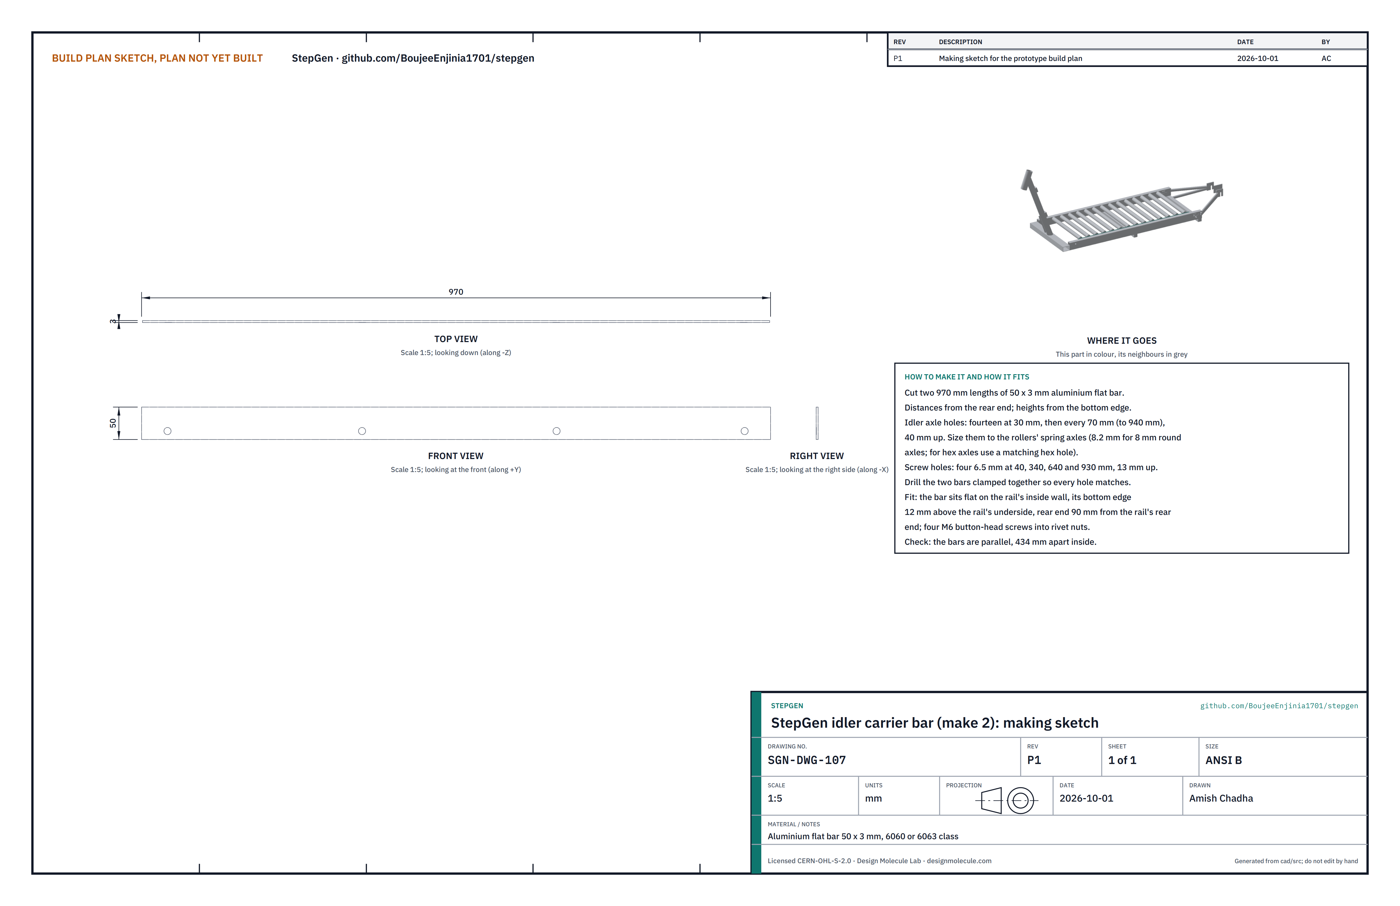
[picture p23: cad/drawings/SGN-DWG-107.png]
Figure 14. Making sketch of the idler carrier bar


*Figure 14. Idler carrier bar making sketch (SGN-DWG-107).*

**What it is and what it is made from.** The flat bar inside each rail that carries the ends of the 14 idler rollers under the belt. Aluminium flat bar 50 x 3 mm, 970 mm long.

**How to make it.**

1. Cut two 970 mm lengths. Clamp them together and drill both at once so every hole matches.
2. Idler holes: fourteen, the first 30 mm from the rear end and then every 70 mm, 40 mm up from the bottom edge. Size them to the rollers' spring axles: 8.2 mm for 8 mm round axles, or a matching hex hole for hex axles.
3. Screw holes: four 6.5 mm holes at 40, 340, 640 and 930 mm, 13 mm up.

**How it fits the parts next to it.** It sits flat on the rail's inside wall, bottom edge 12 mm above the rail's underside, rear end 90 mm from the rail's rear end, held by four M6 button-head screws into the rivet nuts. The idlers' tops are then 237 mm above the ground, just under the belt.

**Check before moving on.** The two bars are parallel and 434 mm apart inside.

### 3.3 Belt, end rollers and idler rollers (bought, from a walking-pad treadmill)

**What to buy.** A used walking-pad treadmill with a belt at least 400 mm wide, or new parts to the same specification: a 400 mm belt loop about 2.2 m round; two 50 mm crowned end rollers about 420 mm long with 6203 size bearings on fixed 17 mm axles; 14 gravity conveyor rollers 30 mm across and 410 mm long with 8 mm spring axles.

**What to do to them.**

1. Front roller: glue a ring of 8 magnets, 24 to 44 mm across, to its left end face, alternate poles out, with epoxy. Drill and tap its axle ends M10 if they are not already.
2. Rear roller: press out the bearing at its right end and press in a one-way bearing of the same size (CSK17 class, 17 x 40 x 12 mm), so the roller turns freely when the belt moves rearward and locks when it would move forward. Cross-drill and tap each axle end M8, 6 mm in from the end, along the vehicle.
3. Make four spacer washers, 22 mm across, to fill the 10 mm between each roller end and the rail.

**How they fit the parts next to them.**

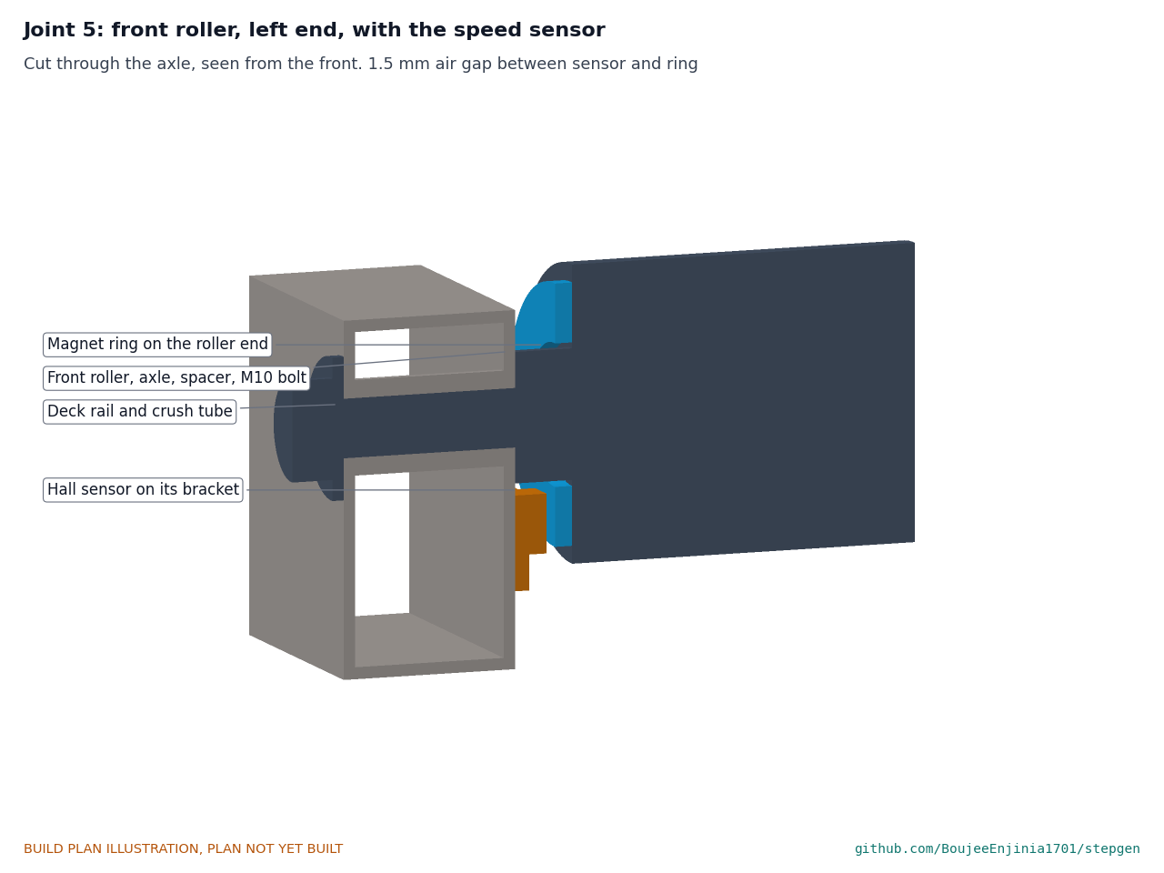
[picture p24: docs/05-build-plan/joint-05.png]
Figure 15. Joint 5: front roller, left end, with the speed sensor


*Figure 15. The front axle is held by an M10 bolt through the rail and its crush tube; the magnet ring on the roller end passes 1.5 mm from the sensor.*

The front roller's axle sits between the rails' inside walls on its spacers and is held by an M10 bolt through each rail. The rear roller's axle runs through the rails' slots and out 12 mm each side, where the M8 tension bolts from the lugs screw into it (Figure 10). The belt loops round both rollers; the idlers sit inside the loop.

**Check before moving on.** The rear roller spins freely one way and locks the other; the front roller spins freely; the magnets are all flush.

### 3.4 Belt drag screw (bought)

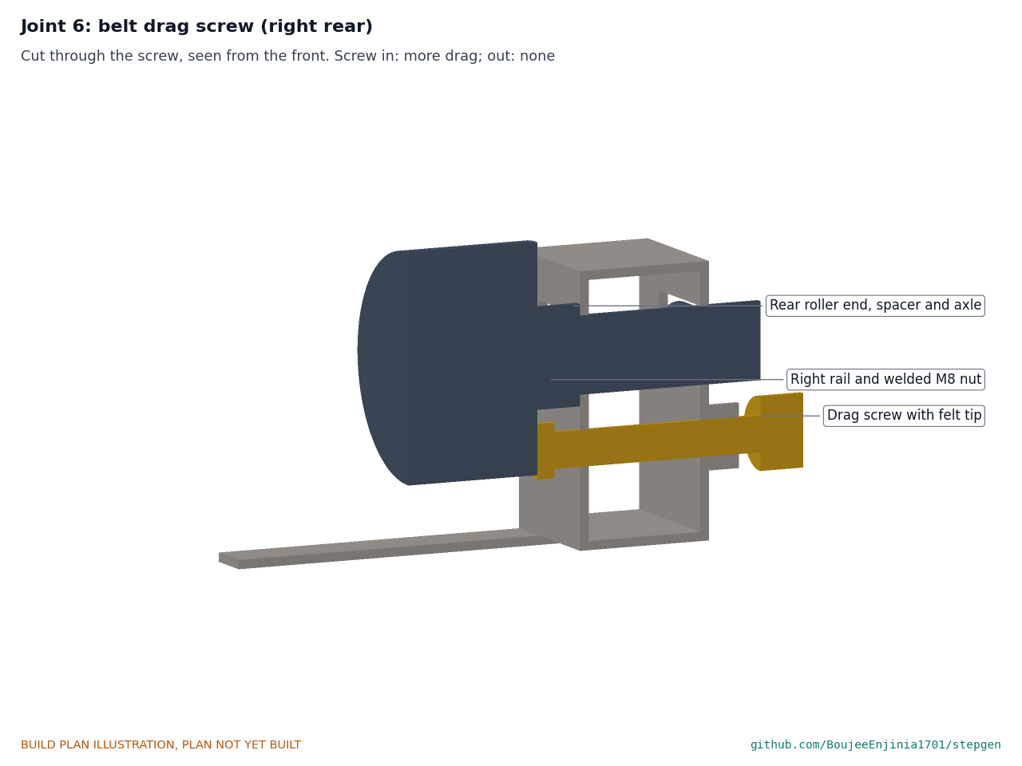
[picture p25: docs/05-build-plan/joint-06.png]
Figure 16. Joint 6: the drag screw


*Figure 16. Cut through the drag screw: its felt tip presses on the rear roller's right end face, 20 mm below the axle.*

**What to buy.** An M8 x 60 mm knurled thumb screw with a 12 mm felt pad glued to its tip, and an M8 lock nut.

**How it fits the parts next to it.** It screws through the nut on the right rail and the rail's two walls; its felt tip presses on the rear roller's end face. Screwing it in adds belt drag, up to about 8 N at the belt; backed off, it adds none. The lock nut holds the setting.

**Check before moving on.** With the screw backed off, the belt pulls by hand with no rubbing.

### 3.5 Sensor bracket

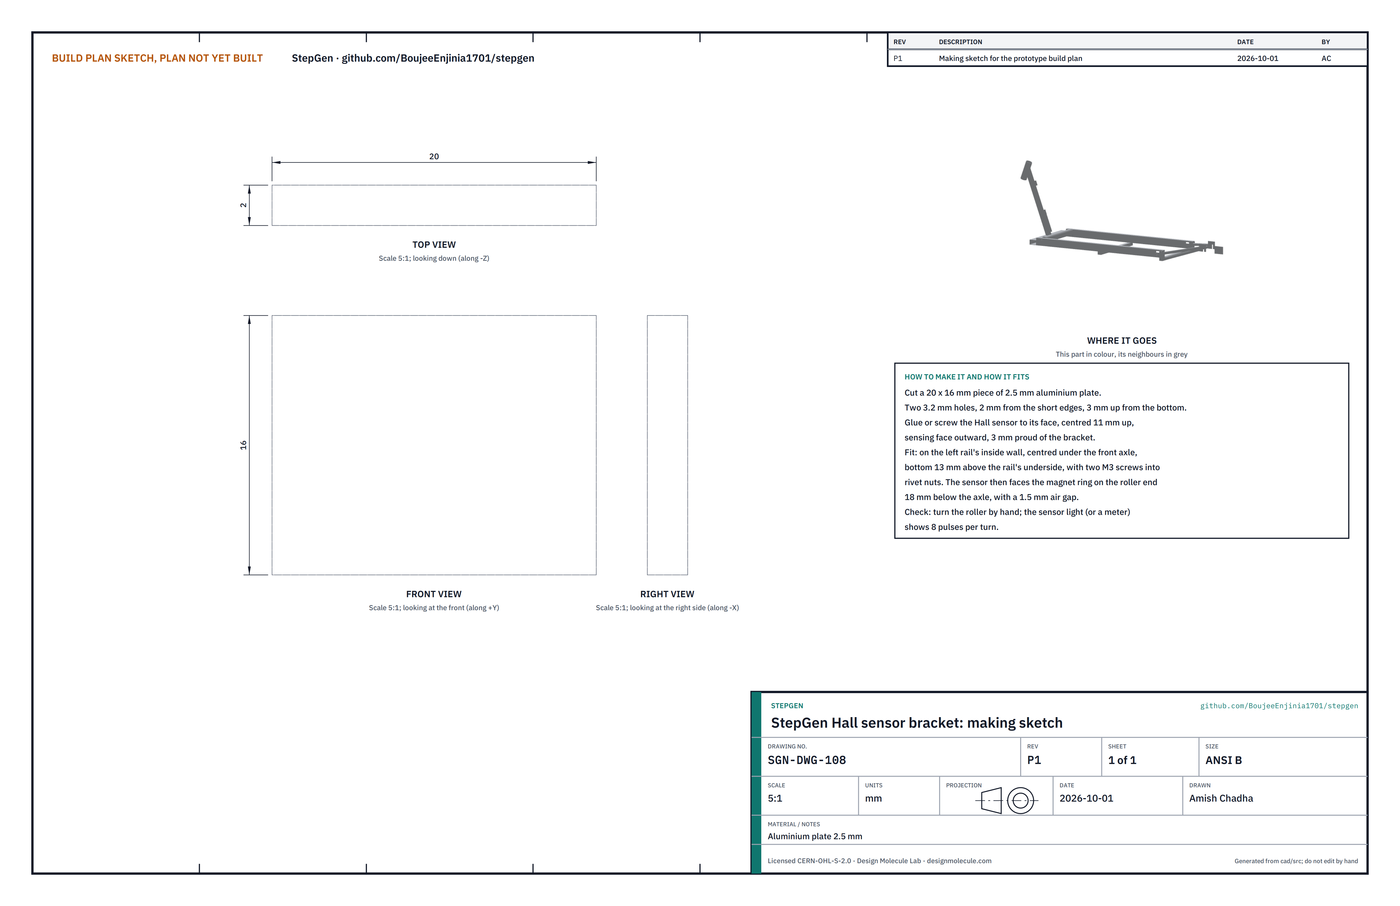
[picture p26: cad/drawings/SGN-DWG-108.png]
Figure 17. Making sketch of the sensor bracket


*Figure 17. Hall sensor bracket making sketch (SGN-DWG-108).*

**What it is and what it is made from.** A small plate that holds the belt speed sensor facing the magnet ring. Aluminium plate 2.5 mm, 20 x 16 mm.

**How to make it.** Cut the plate; drill two 3.2 mm holes, 2 mm from the short edges and 3 mm up from the bottom; glue or screw the Hall sensor to its face, centred 11 mm up, sensing face outward and 3 mm proud.

**How it fits the parts next to it.** On the left rail's inside wall, centred under the front axle, held by two M3 screws into the rivet nuts; the sensor faces the magnet ring 18 mm below the axle (Figure 15).

**Check before moving on.** Turning the roller by hand gives 8 pulses per turn on a meter or the sensor's light.

### 3.6 Steering column

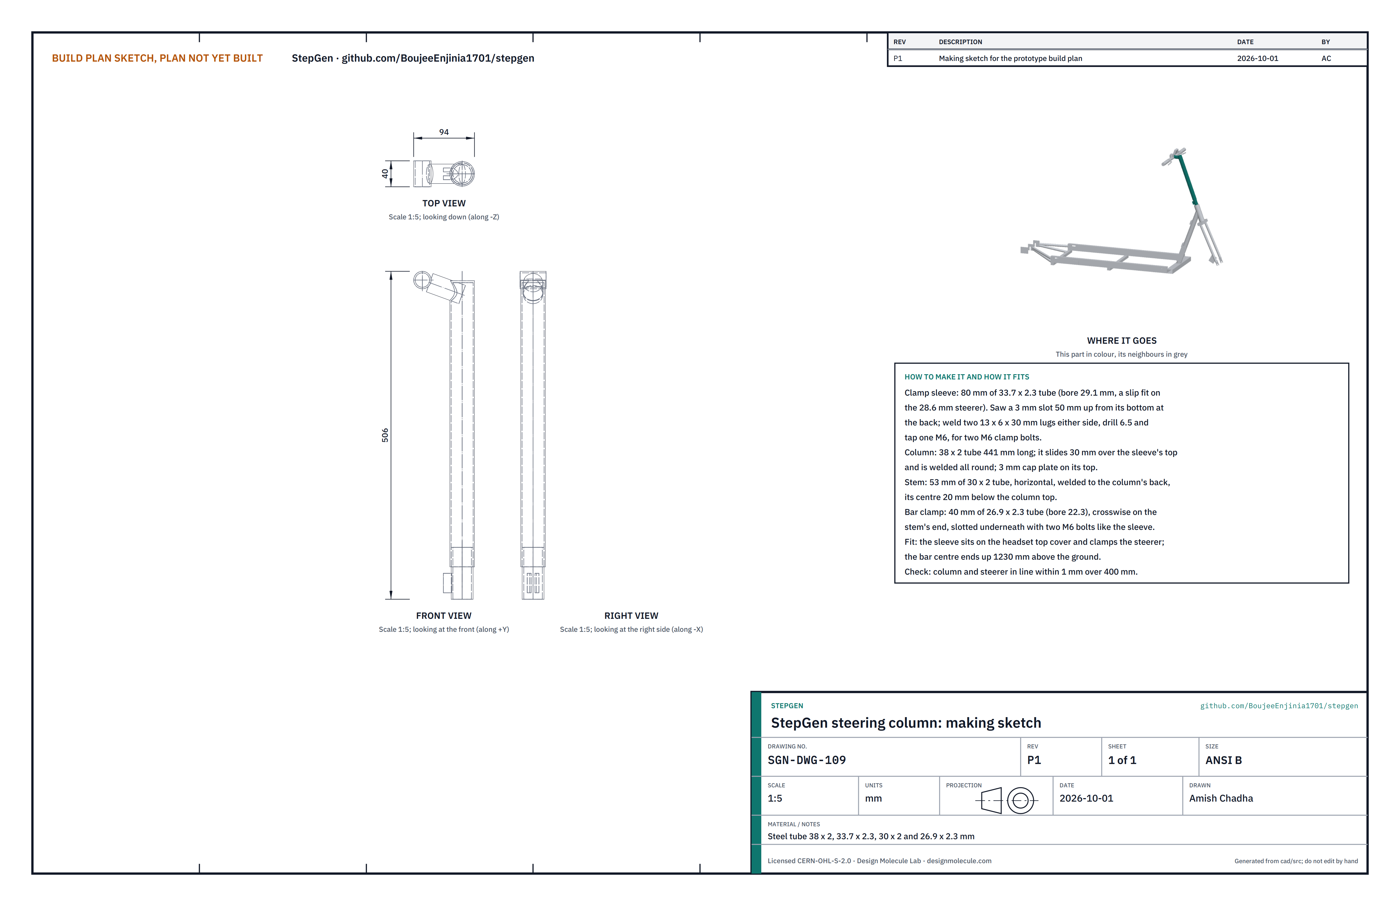
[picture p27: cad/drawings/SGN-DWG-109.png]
Figure 18. Making sketch of the steering column


*Figure 18. Steering column making sketch (SGN-DWG-109), drawn along the steering axis.*

**What it is and what it is made from.** The welded column that clamps the fork's steerer above the headset and carries the handlebar at 1.23 m. Steel tube in four stock sizes that slide inside each other: 33.7 x 2.3 mm (sleeve), 38 x 2 mm (column), 30 x 2 mm (stem) and 26.9 x 2.3 mm (bar clamp).

**How to make it.**

1. Sleeve: cut 80 mm of 33.7 x 2.3 mm tube (bore 29.1 mm, a slip fit on the 28.6 mm steerer). Saw a 3 mm slot 50 mm up from its bottom at the back. Weld two 13 x 6 x 30 mm lugs either side of the slot; drill both 6.5 mm and tap the far one M6.
2. Column: cut 441 mm of 38 x 2 mm tube. Slide it 30 mm over the top of the sleeve and weld all round. Weld a 3 mm cap plate on its top.
3. Stem: cut 53 mm of 30 x 2 mm tube; fish-mouth one end to the column. Weld it to the back of the column, level, its centre 20 mm below the column top.
4. Bar clamp: cut 40 mm of 26.9 x 2.3 mm tube (bore 22.3 mm). Weld it crosswise on the stem's free end. Slot it underneath and add two lugs and an M6 bolt as for the sleeve.

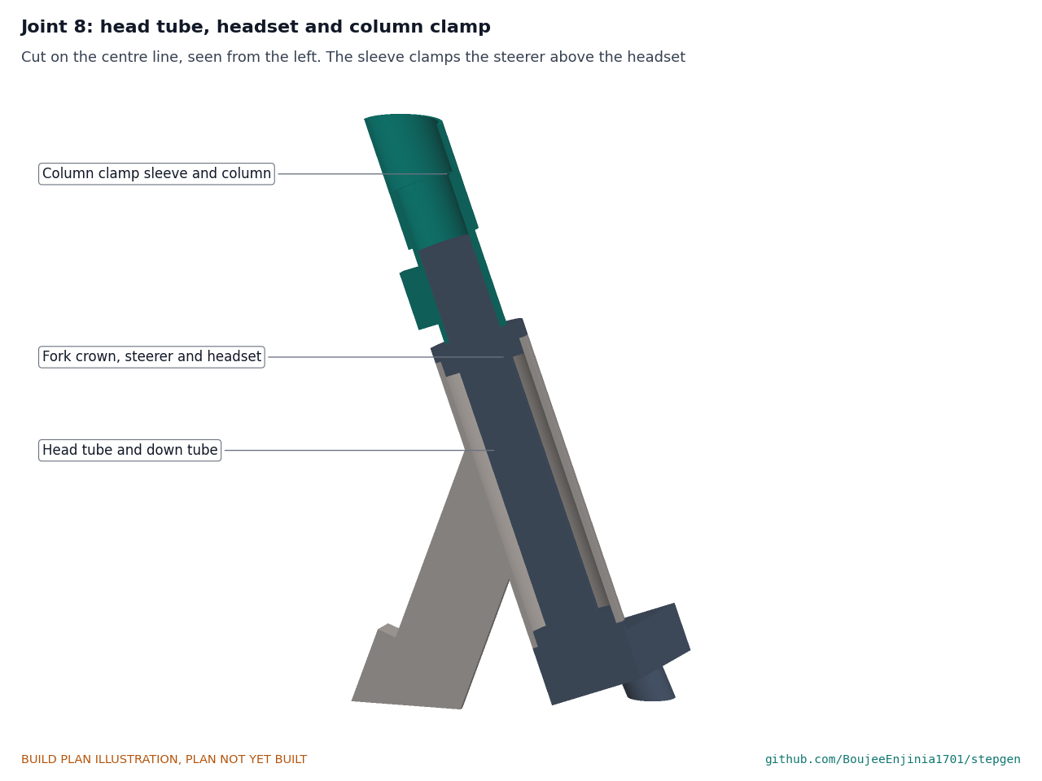
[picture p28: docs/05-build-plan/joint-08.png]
Figure 19. Joint 8: head tube, headset and column clamp


*Figure 19. Cut on the centre line: the headset sits in the head tube, the column's sleeve sits on the headset's top cover and clamps the steerer. The down tube joins the head tube's side.*

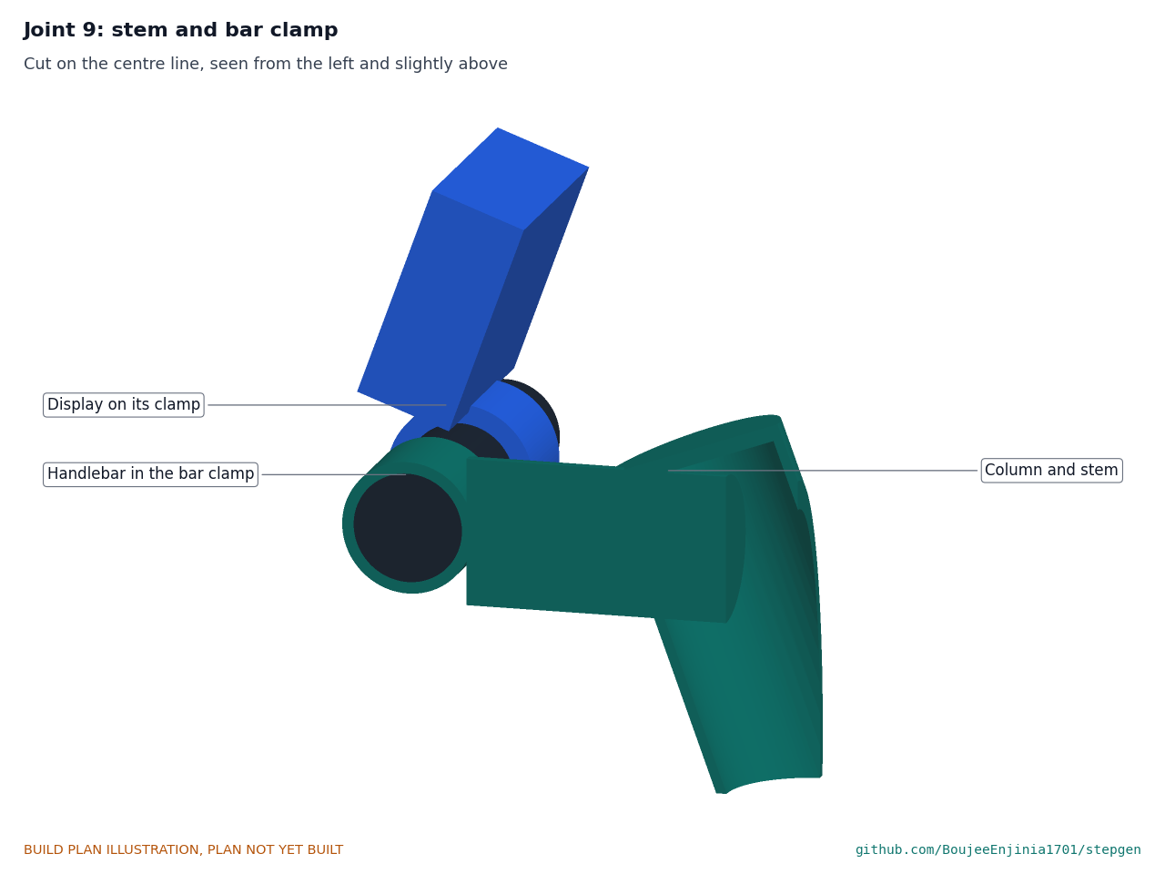
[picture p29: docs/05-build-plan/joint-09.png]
Figure 20. Joint 9: stem and bar clamp


*Figure 20. The bar clamp on the stem's end holds the handlebar; the display clamps beside it.*

**How it fits the parts next to it.** The sleeve sits on the headset's top cover and clamps the steerer with its two bolts (Figure 19); the bar clamp holds the 22.2 mm handlebar (Figure 20).

**Check before moving on.** On a straight 28.6 mm bar, column and bar are in line within 1 mm over 400 mm, and the stem is square to the column.

### 3.7 Receiver cradle

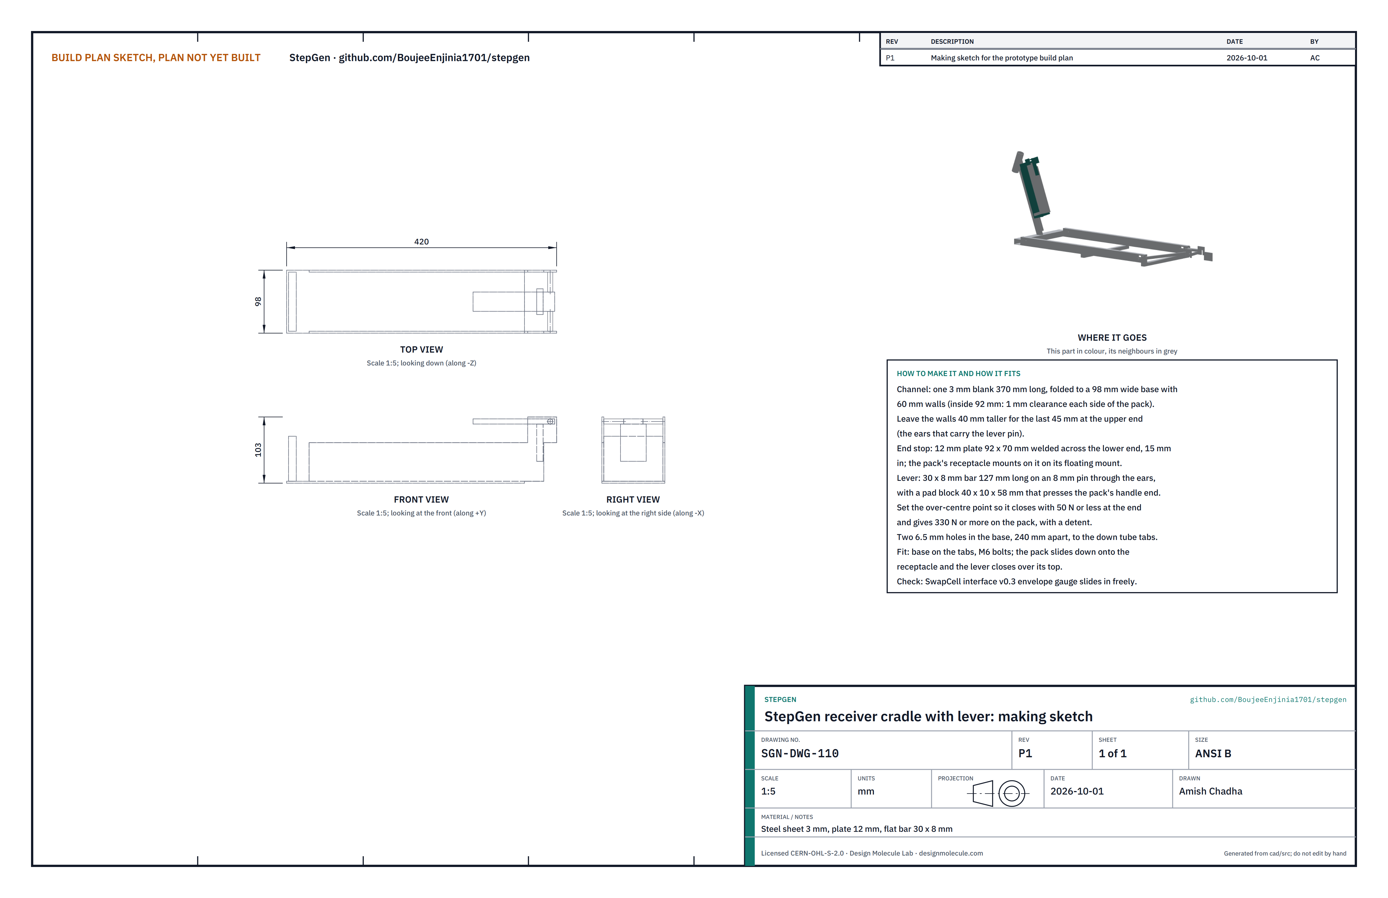
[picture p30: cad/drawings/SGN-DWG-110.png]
Figure 21. Making sketch of the receiver cradle


*Figure 21. Receiver cradle making sketch (SGN-DWG-110).*

**What it is and what it is made from.** The SwapCell receiver to latch class V1: a folded steel channel that the pack slides into, an end stop carrying the pack's connector, and an over-centre lever that presses the pack onto it. Steel sheet 3 mm, plate 12 mm, flat bar 30 x 8 mm.

**How to make it.**

1. Channel: cut one 3 mm blank 370 mm long and fold it to a base 98 mm wide with 60 mm walls, so it is 92 mm wide inside (1 mm clearance each side of the pack). Leave the last 45 mm of each wall at the upper end 40 mm taller (the ears).
2. End stop: cut 12 mm plate to 92 x 70 mm and weld it across the lower end, 15 mm in from the channel's end. Mount the pack's receptacle on it on its floating mount.
3. Lever: a 127 mm length of 30 x 8 mm bar on an 8 mm pin through the ears, with a pad block 40 x 10 x 58 mm welded under it that presses the pack's handle end. Set the over-centre point so it closes with 50 N or less at its end and holds 330 N or more on the pack, with a detent.
4. Base: two 6.5 mm holes, 240 mm apart, to match the down tube's tabs.

**How it fits the parts next to it.**

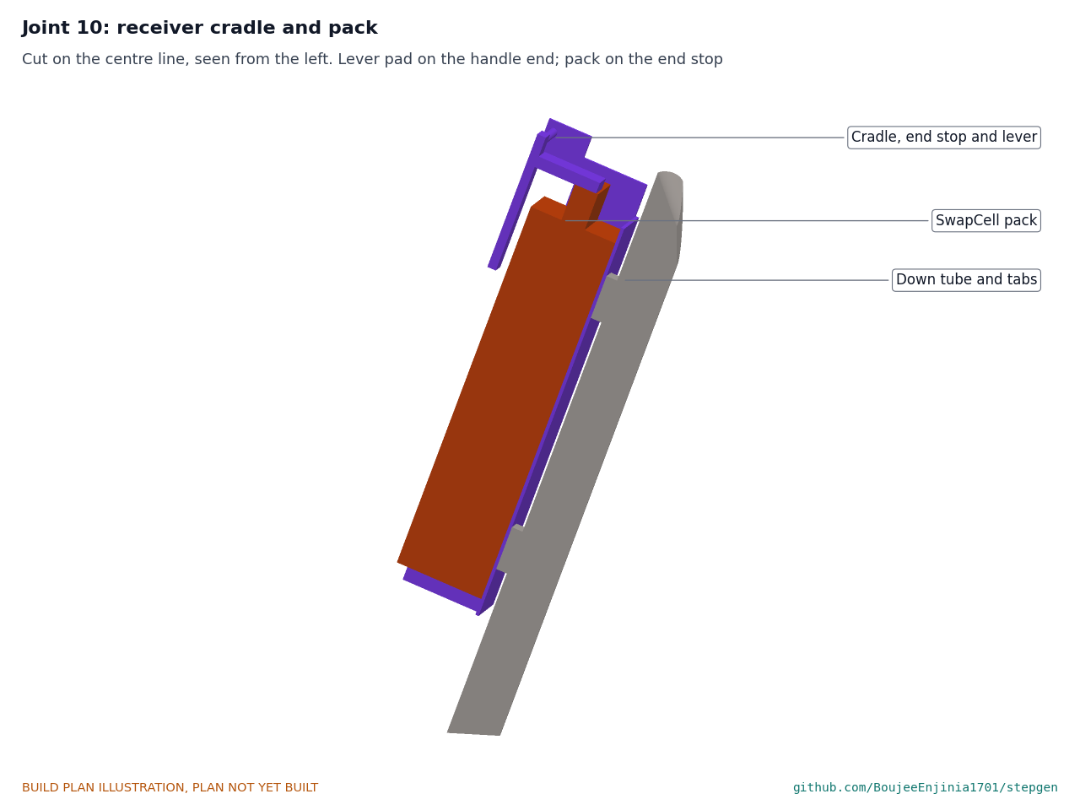
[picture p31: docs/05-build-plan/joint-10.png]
Figure 22. Joint 10: receiver cradle and pack


*Figure 22. Cut on the centre line: the pack sits on the base against the end stop; the lever's pad presses its handle end.*

The base sits on the two tabs on the down tube, two M6 bolts. The pack slides down the channel onto the receptacle and the lever closes over its top.

**Check before moving on.** A SwapCell interface v0.3 envelope gauge slides in and out freely; the lever snaps over centre.

### 3.8 Heel guard

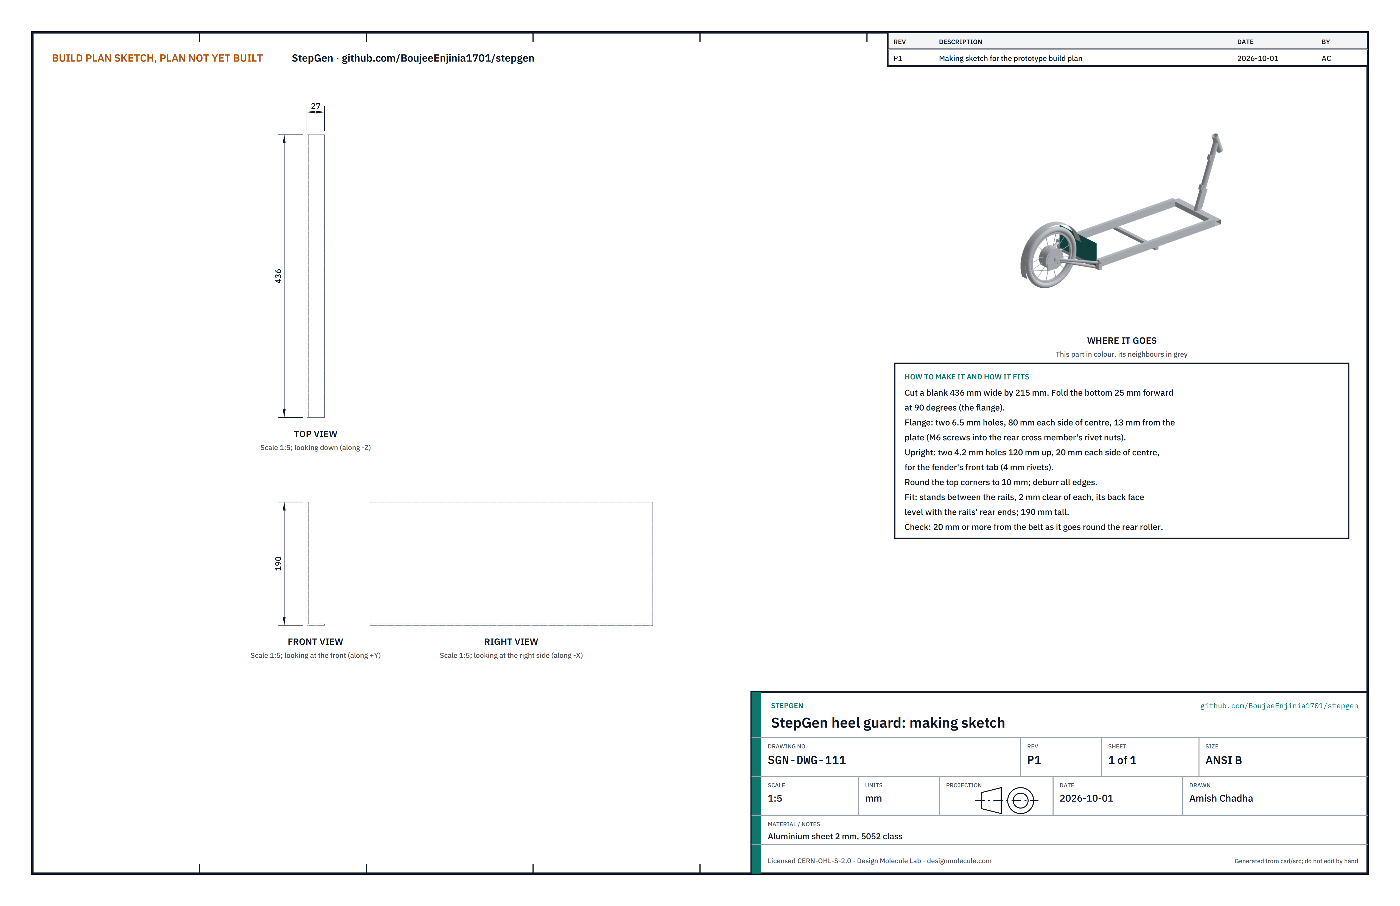
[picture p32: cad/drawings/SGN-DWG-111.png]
Figure 23. Making sketch of the heel guard


*Figure 23. Heel guard making sketch (SGN-DWG-111).*

**What it is and what it is made from.** The upright plate between the rear end of the belt and the rear tire. Aluminium sheet 2 mm, 5052 class.

**How to make it.**

1. Cut a blank 436 x 215 mm. Fold the bottom 25 mm forward at 90 degrees (the flange).
2. Flange: two 6.5 mm holes, 80 mm each side of centre, 13 mm from the upright.
3. Upright: two 4.2 mm holes 120 mm up, 20 mm each side of centre, for the fender's front tab.
4. Round the top corners to 10 mm; deburr all edges.

**How it fits the parts next to it.** It stands between the rails, 2 mm clear of each, its back face level with the rails' rear ends, 190 mm tall; the flange lies on the rear cross member, two M6 screws into the rivet nuts. The fender's front end is riveted to it (Figure 25).

**Check before moving on.** At least 20 mm from the belt where it turns round the rear roller.

### 3.9 Roller covers (a rear and a front)

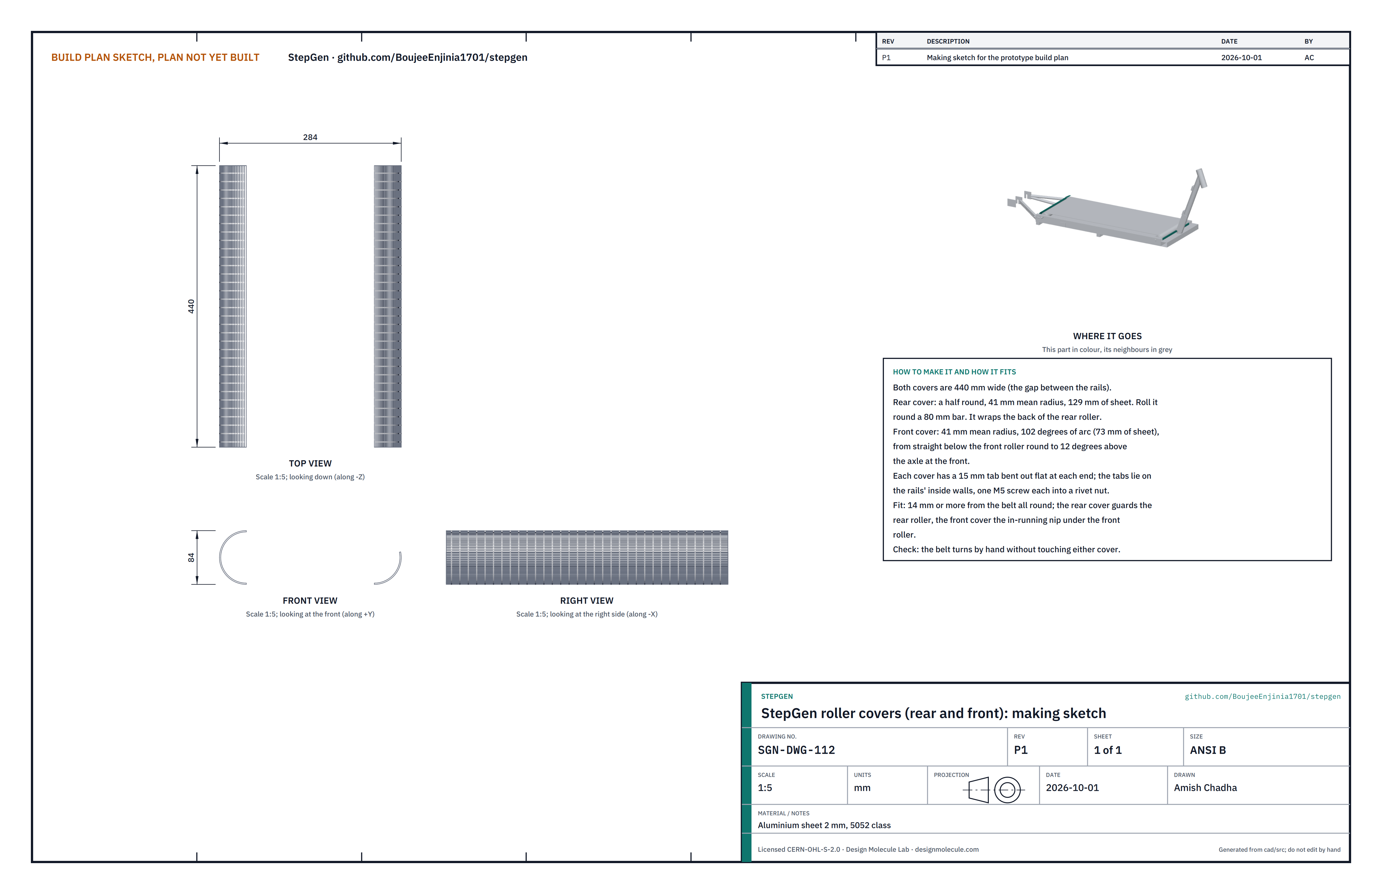
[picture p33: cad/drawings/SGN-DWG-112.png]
Figure 24. Making sketch of the roller covers


*Figure 24. Roller covers making sketch (SGN-DWG-112).*

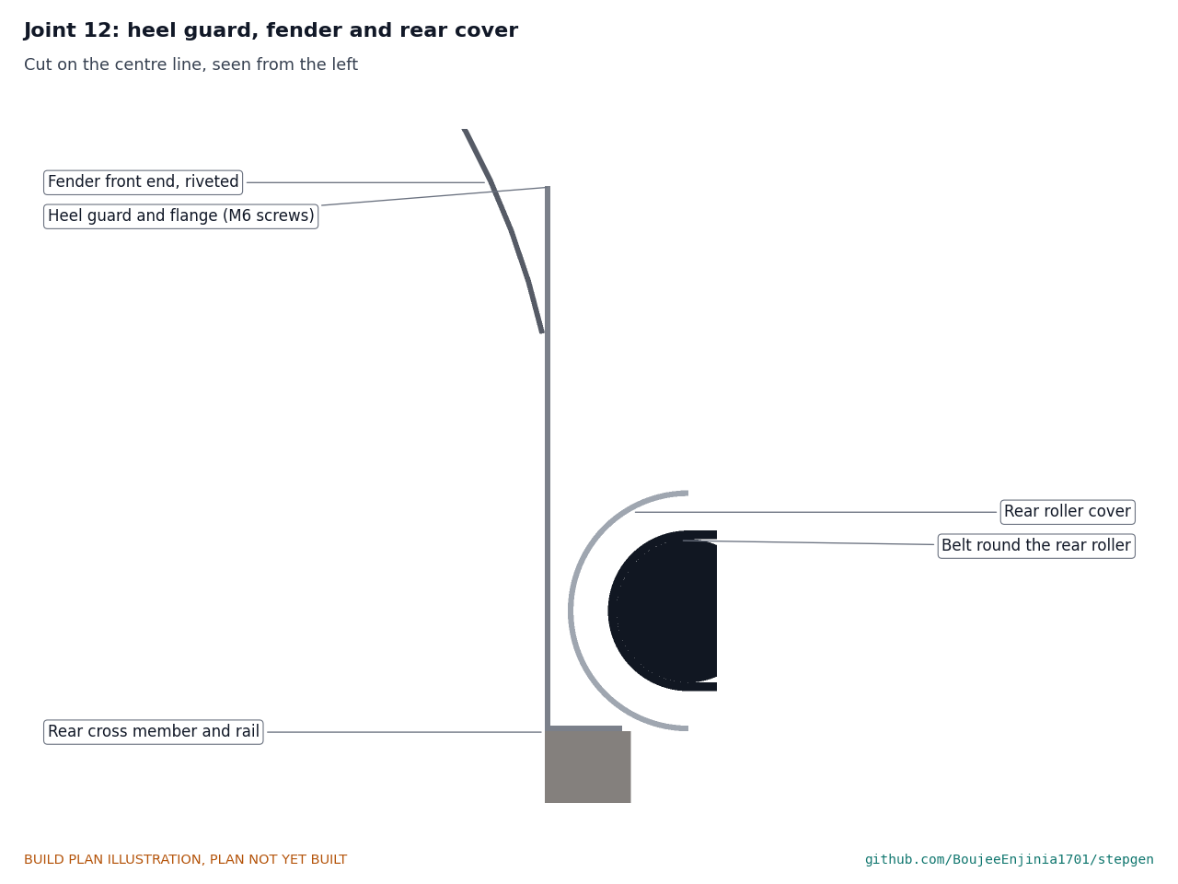
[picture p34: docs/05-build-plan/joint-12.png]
Figure 25. Joint 12: heel guard, fender and rear cover


*Figure 25. Cut on the centre line: the heel guard's flange on the rear cross member, the fender riveted to the heel guard, and the rear cover round the back of the rear roller.*

**What they are and what they are made from.** Curved guards over the belt where it turns round each end roller. Aluminium sheet 2 mm, 440 mm wide.

**How to make them.**

1. Rear cover: 129 mm of sheet rolled round an 80 mm bar to a half round, 41 mm mean radius.
2. Front cover: 73 mm of sheet rolled to the same radius (a 102 degree arc).
3. Bend a 15 mm tab out flat at each end of each cover; drill one 5.5 mm hole in each tab.

**How they fit the parts next to them.** The rear cover wraps the back of the rear roller; the front cover runs from straight under the front roller round to just above its axle at the front, covering the nip where the belt runs onto the roller. Each tab lies on a rail's inside wall, one M5 screw into a rivet nut set where the tab falls. Each cover is at least 14 mm from the belt.

**Check before moving on.** The belt turns by hand without touching either cover.

### 3.10 Toe guard

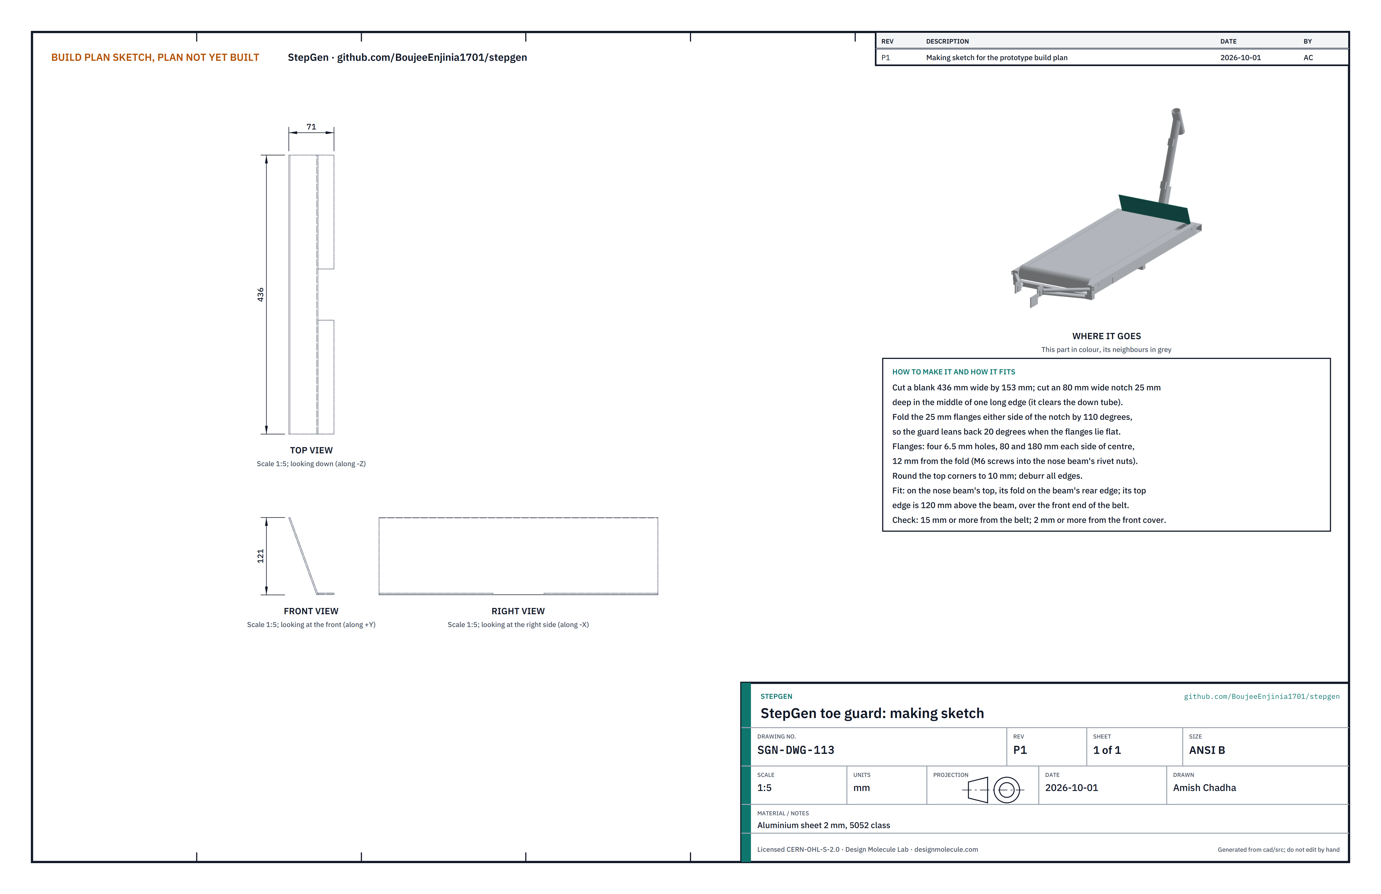
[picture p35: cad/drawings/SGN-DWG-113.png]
Figure 26. Making sketch of the toe guard


*Figure 26. Toe guard making sketch (SGN-DWG-113).*

**What it is and what it is made from.** The plate across the front end of the belt that stops the rider's toes. Aluminium sheet 2 mm.

**How to make it.**

1. Cut a blank 436 x 153 mm; cut an 80 mm wide notch, 25 mm deep, in the middle of one long edge.
2. Fold the 25 mm flanges either side of the notch by 110 degrees, so the guard leans back 20 degrees when the flanges lie flat.
3. Flanges: four 6.5 mm holes, 80 and 180 mm each side of centre, 12 mm from the fold. Round the top corners; deburr.

**How it fits the parts next to it.** The flanges lie on the nose beam's top, fold on its rear edge, notch round the down tube, four M6 screws into the rivet nuts (Figure 6). Its top edge is 120 mm above the beam, over the front end of the belt.

**Check before moving on.** At least 15 mm from the belt and 2 mm from the front cover.

### 3.11 Side boards (make 2) and spacers

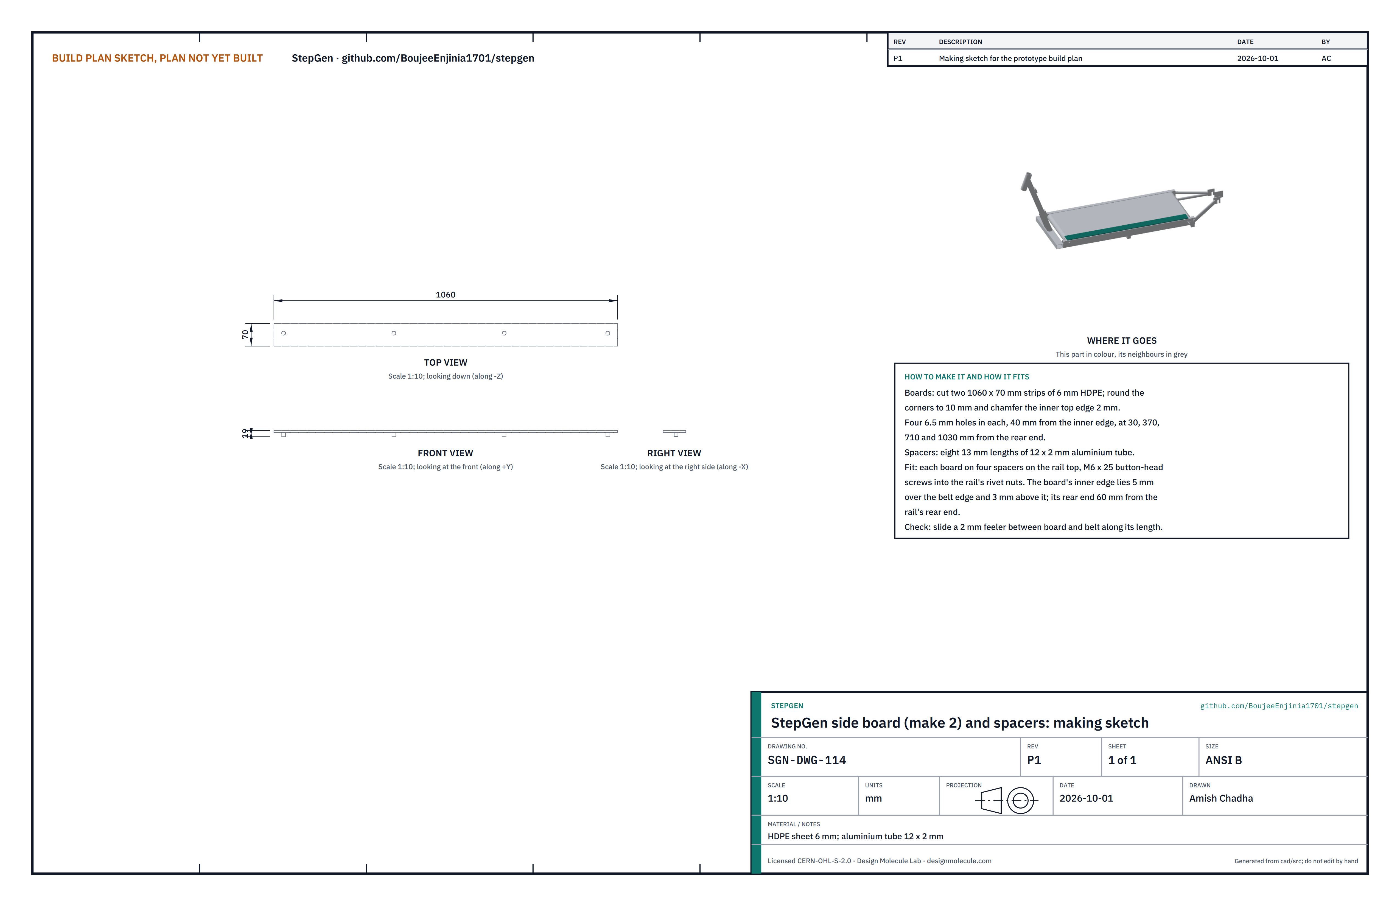
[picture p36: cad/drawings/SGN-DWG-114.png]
Figure 27. Making sketch of the side board


*Figure 27. Side board making sketch (SGN-DWG-114).*

**What they are and what they are made from.** The flat strips over each rail that cover the belt edges and give a firm place to put a foot. HDPE sheet 6 mm; aluminium tube 12 x 2 mm for the spacers.

**How to make them.**

1. Cut two 1060 x 70 mm strips; round the corners to 10 mm and chamfer the inner top edge 2 mm.
2. Drill four 6.5 mm holes in each, 40 mm from the inner edge, at 30, 370, 710 and 1030 mm from the rear end.
3. Cut eight 13 mm lengths of 12 x 2 mm tube (the spacers).

**How they fit the parts next to them.** Each board sits on four spacers on the rail top, held by M6 x 25 mm button-head screws into the rail's rivet nuts (Figure 13). Its inner edge lies 5 mm over the belt edge and 3 mm above it; its rear end is 60 mm from the rail's rear end.

**Check before moving on.** A 2 mm feeler slides between board and belt along the whole length.

### 3.12 Bought components

Buy to specification, not brand. Line numbers are those of the bill of materials.

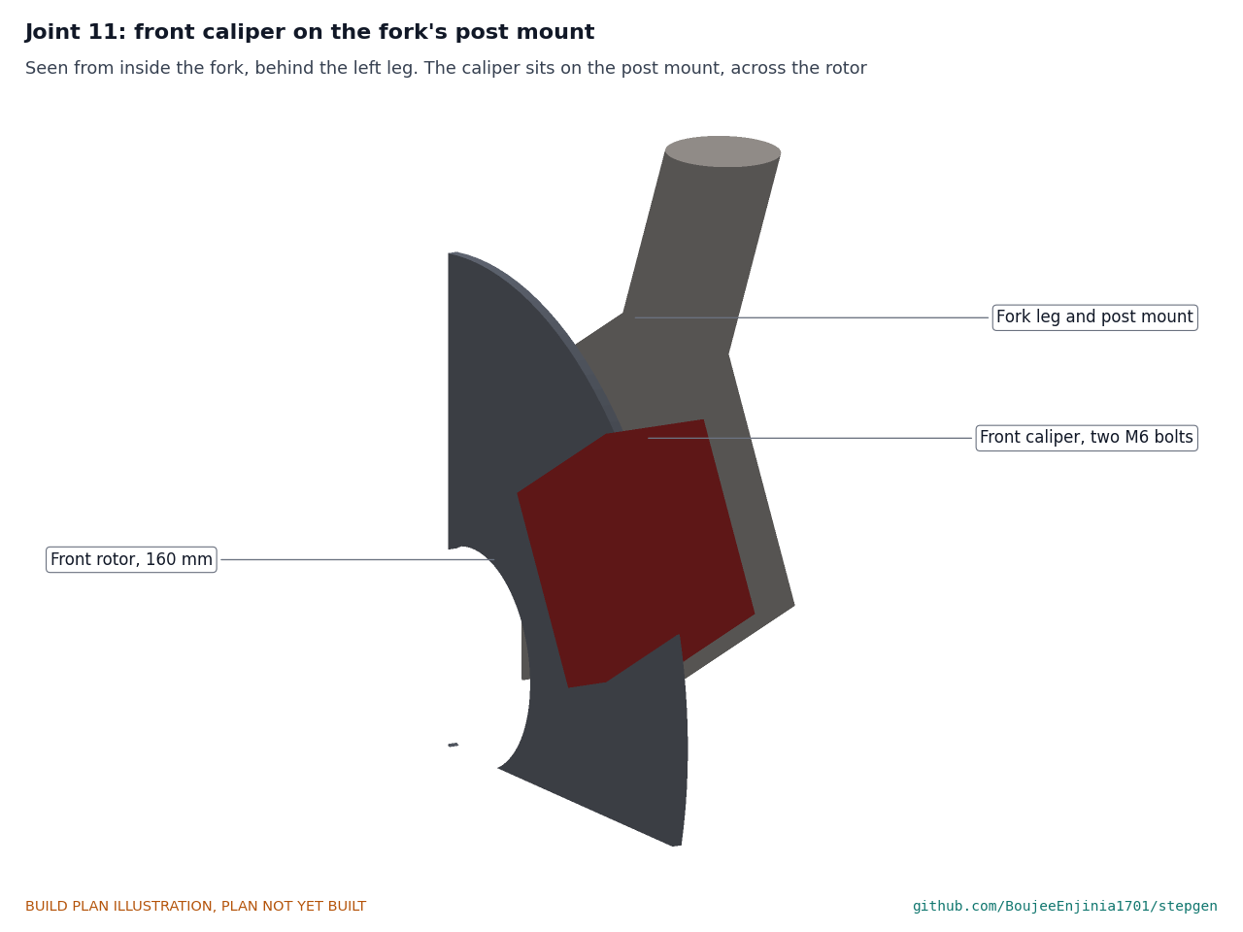
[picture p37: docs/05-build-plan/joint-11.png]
Figure 28. Joint 11: front caliper on the fork's post mount


*Figure 28. The front caliper bolts to the post mount behind the left fork leg, straddling the rotor.*

- **Fork and headset (line 7).** A 1 1/8 in threadless steel rigid fork with post-mount disc tabs, for 26 in wheels (axle to crown about 410 mm), 30 mm offset, 100 mm hub spacing, steerer at least 220 mm; a ZS44 semi-integrated headset. Cut the steerer so it ends 3 mm below the top of the column's sleeve.
- **Front wheel (line 7).** 20 in (ETRTO 406) with a 6-bolt disc hub, 100 mm spacing, tire 20 x 1.75 in and tube. From a donor 20 in bike, or new.
- **Rear wheel with hub motor (line 6).** A 48 V 250 W geared hub motor for a 20 in wheel, 135 mm axle width, 6-bolt rotor mount, laced into a 20 in rim with a 20 x 1.75 in tire; two torque arms to fit its axle flats.
- **Brakes (line 9).** Two mechanical disc calipers for 160 mm rotors (post mount), two 6-bolt 160 mm rotors, two levers with built-in motor cut-off switches, cables.
- **Controller and logic board (line 12).** A 48 V (to 54.6 V), 15 A sine-wave hub motor controller with brake-cut and speed-command inputs, in a case no larger than 150 x 70 x 40 mm; an ESP32 board with a CAN transceiver and a 60 V input buck converter. No firmware is written at this stage.
- **Controls (line 13).** Handlebar display for speed, level and charge; three-position level selector; key switch; magnetic lanyard stop switch with a wrist or belt clip; each with its own 22.2 mm bar clamp.
- **Handlebar and grips (line 8).** A straight 580 mm flat bar, 22.2 mm, steel or aluminium; grips 130 mm long.
- **Harness (line 15).** Waterproof keyed connectors, a 20 A blade fuse in a sealed holder, cable and two grommets, spiral wrap, cable ties.
- **Kickstand (line 16).** A side kickstand with a two-bolt plate, about 230 mm long, for 20 in wheels.
- **Fender (line 14).** A 20 in rear fender, 60 mm wide, with two stays and a front tab.
- **Fixings (lines 3, 14 and 16).** M6 rivet nuts (22), M3 rivet nuts (2), M5 rivet nuts (4); M6 button-head screws and washers; two M10 bolts for the front axle; two M8 x 60 mm tension bolts with lock nuts; four M6 bolts for the calipers.
- **SwapCell pack (line 11).** Built by the SwapCell project to interface v0.3; not part of this build's parts cost.

## 4. Putting it together

In each picture the parts already fitted are grey and the part being fitted is in colour, with an arrow showing the way it goes in.

### Step 1: kickstand onto the frame

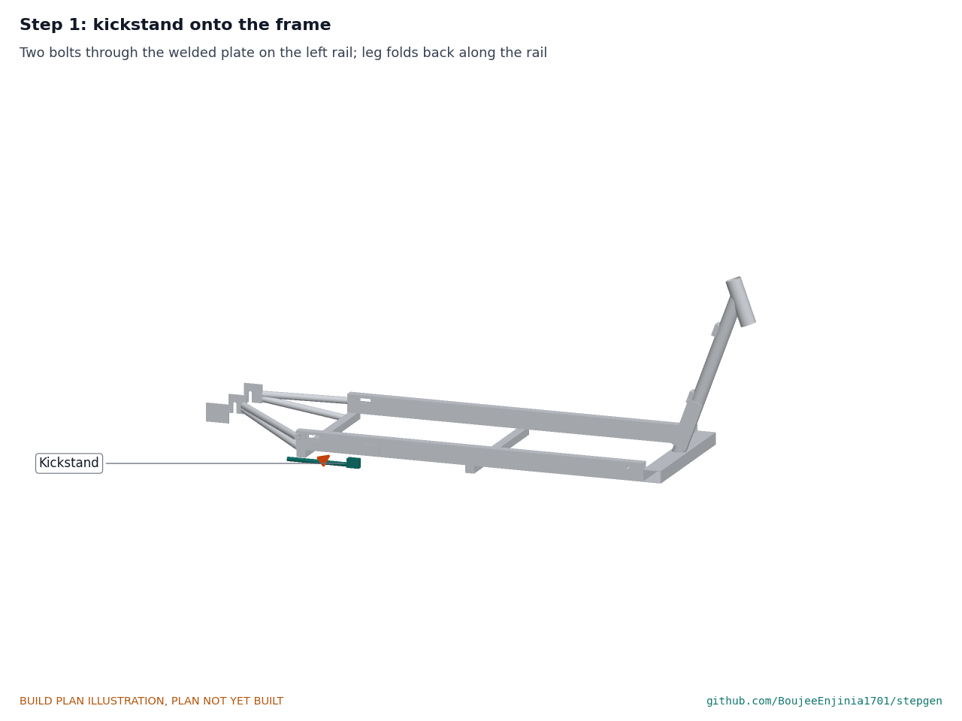
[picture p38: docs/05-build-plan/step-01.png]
Step 1


Two bolts through the plate on the left rail, nyloc nuts; the leg folds back along the rail.

### Step 2: idler carrier bars into the rails

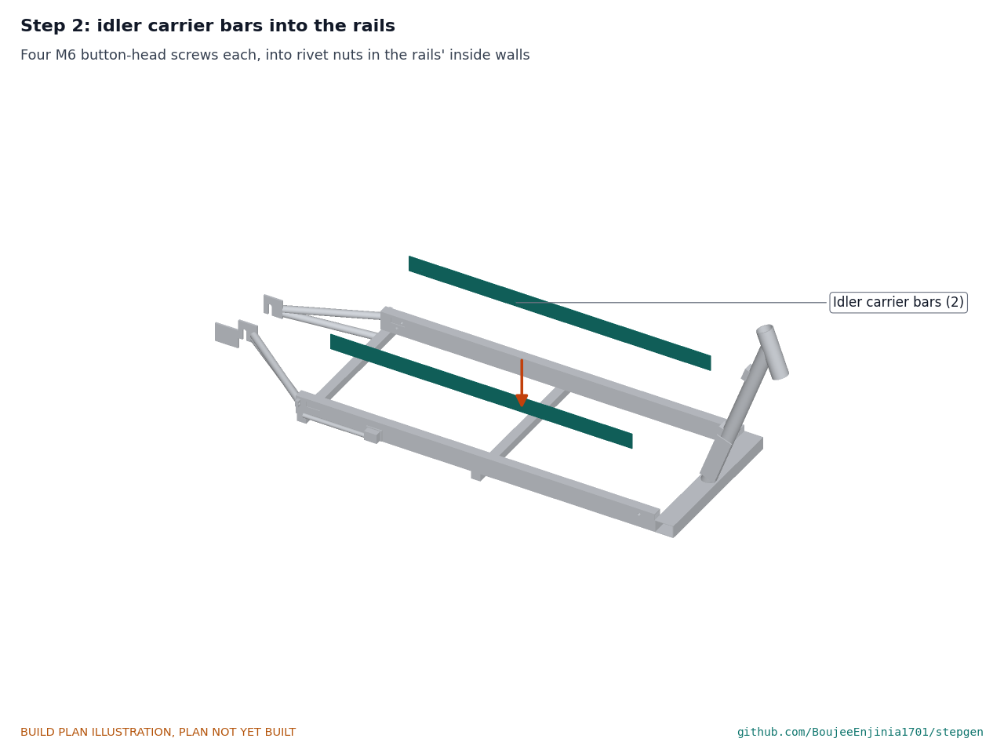
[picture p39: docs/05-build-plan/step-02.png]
Step 2


Four M6 button-head screws each, into the rivet nuts in the rails' inside walls.

### Step 3: belt between the rails, front roller into it

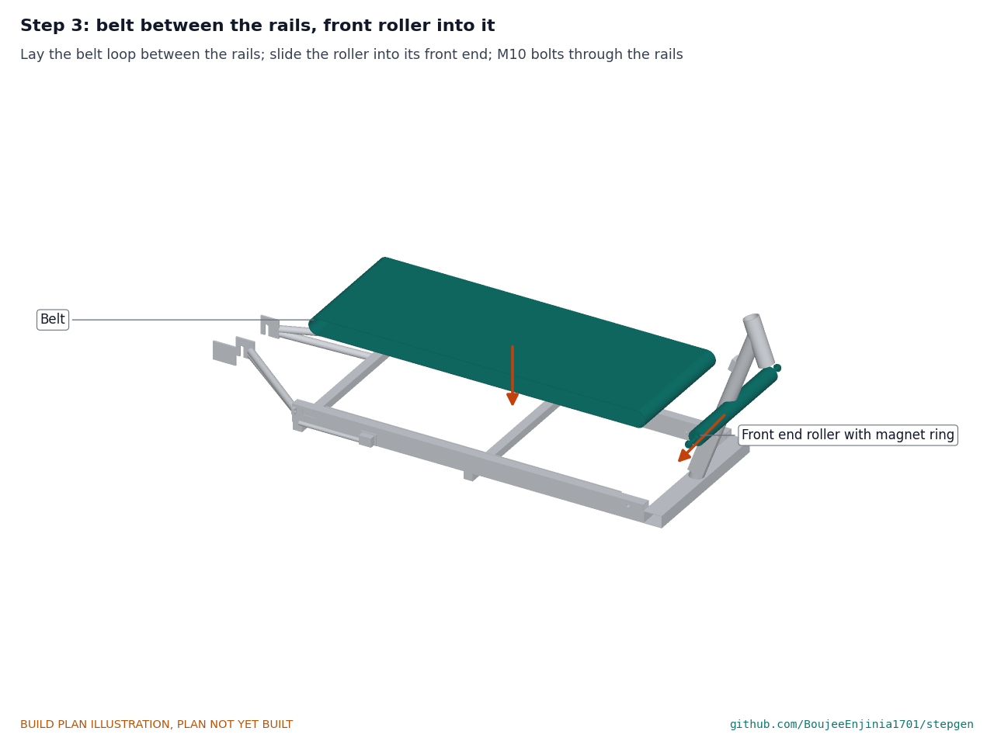
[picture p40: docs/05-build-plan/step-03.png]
Step 3


Lay the belt loop between the rails. Slide the front roller, with its spacers, into the loop's front end, line its axle up with the rails' holes, and fit an M10 bolt and washer through each rail into the axle. Tighten so the axle cannot turn.

### Step 4: rear roller into the belt and the rail slots

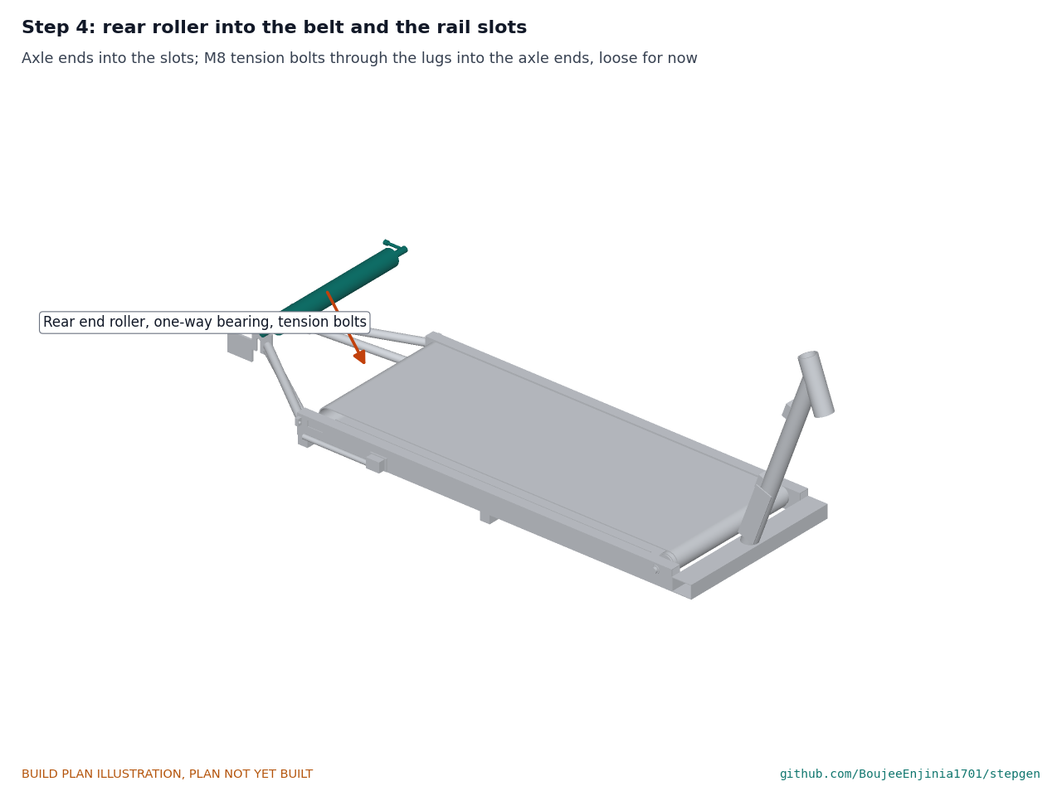
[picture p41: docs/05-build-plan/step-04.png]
Step 4


Slide the rear roller, with its spacers, into the loop's rear end; its axle ends drop into the slots in both rails. Fit an M8 tension bolt through each lug into the axle end, finger tight.

### Step 5: idler rollers into the belt loop

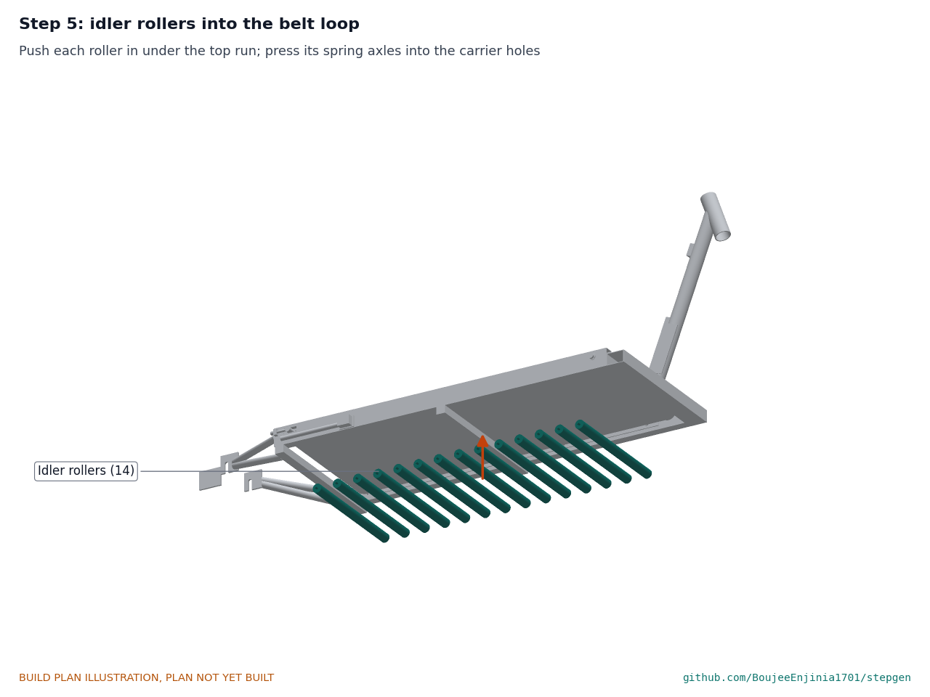
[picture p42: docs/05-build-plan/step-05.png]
Step 5


Seen from below. Push each idler in under the belt's top run and press its spring axles into a pair of holes in the carrier bars. Then tension the belt: turn both tension bolts evenly until the belt is held at about 500 N each side (it lifts about 10 mm with a 50 N pull at its middle), then centre its tracking by turning one bolt a quarter turn at a time. Lock the bolts with their nuts. **Hold point:** the belt turns by hand rearward and will not move forward.

### Step 6: drag screw and speed sensor

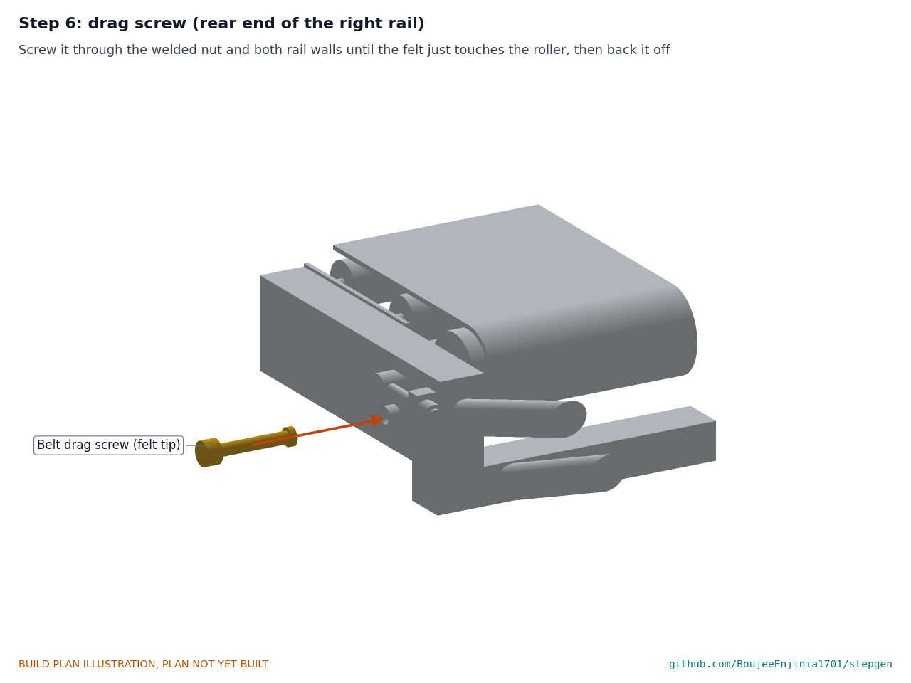
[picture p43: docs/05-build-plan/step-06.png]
Step 6, drag screw


Drag screw through the welded nut on the right rail until its felt just touches the rear roller's end, then back it off and fit the lock nut.

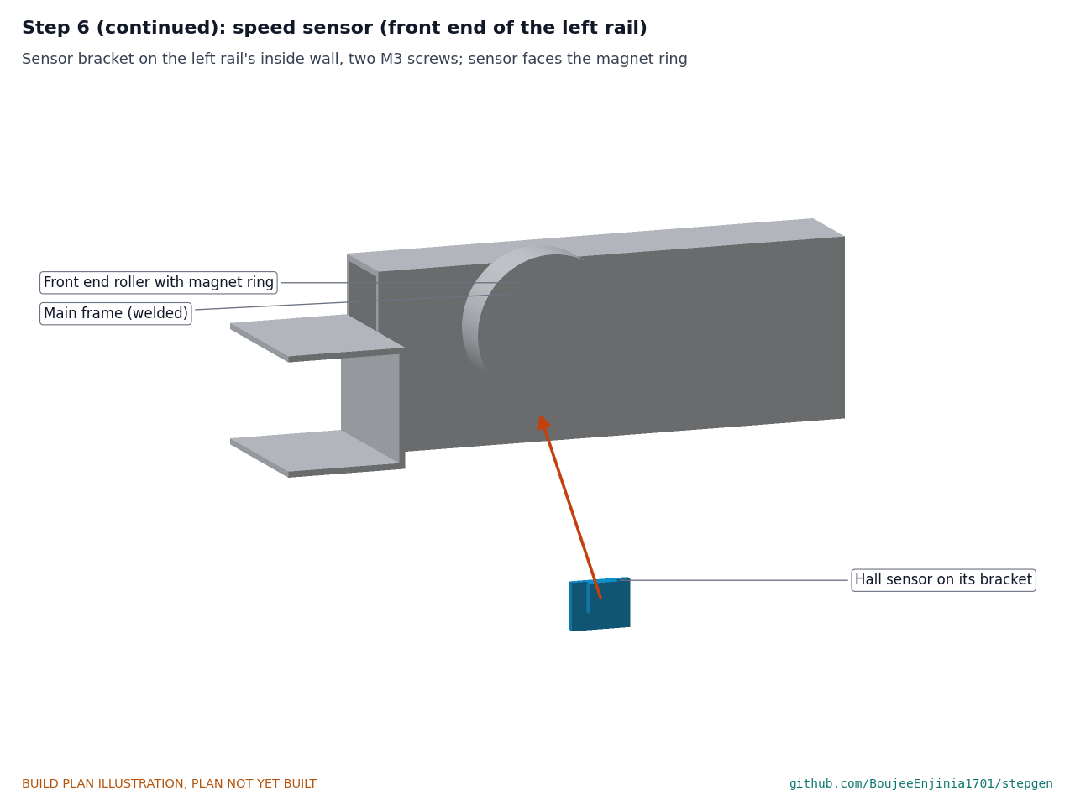
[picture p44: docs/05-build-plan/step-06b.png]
Step 6, speed sensor


Sensor bracket on the left rail's inside wall under the front axle, two M3 screws, the sensor facing the magnet ring; run its cable through the rail's front grommet.

### Step 7: fork and headset into the head tube

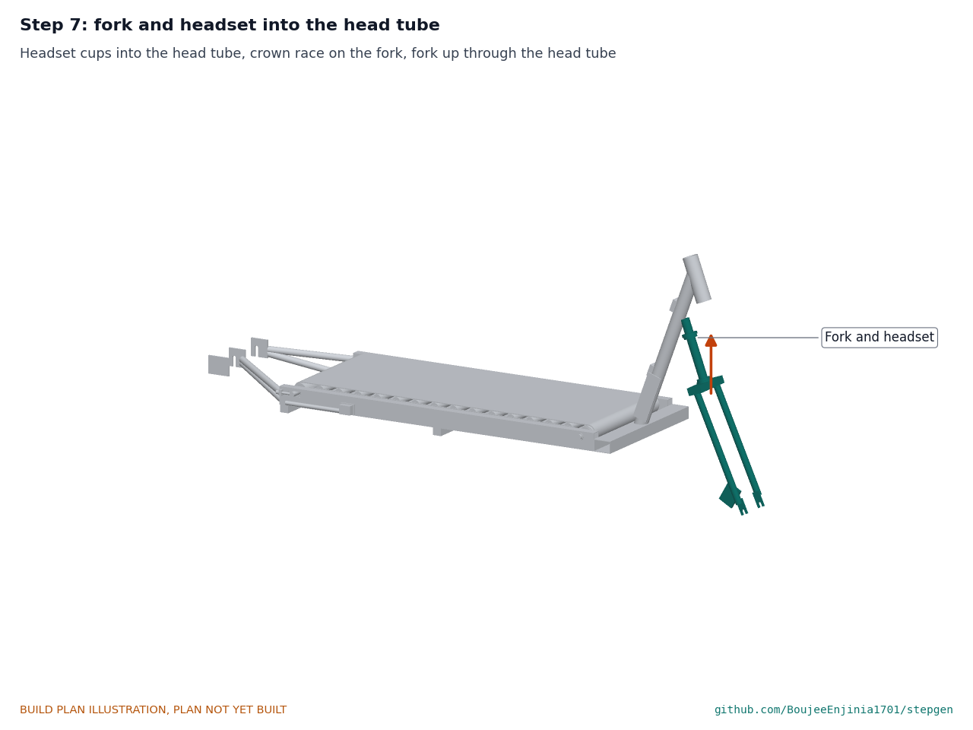
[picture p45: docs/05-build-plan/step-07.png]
Step 7


Press the headset cups into the head tube, fit the crown race on the fork, grease the bearings, and slide the fork up through the head tube. Fit the top cover.

### Step 8: steering column onto the steerer

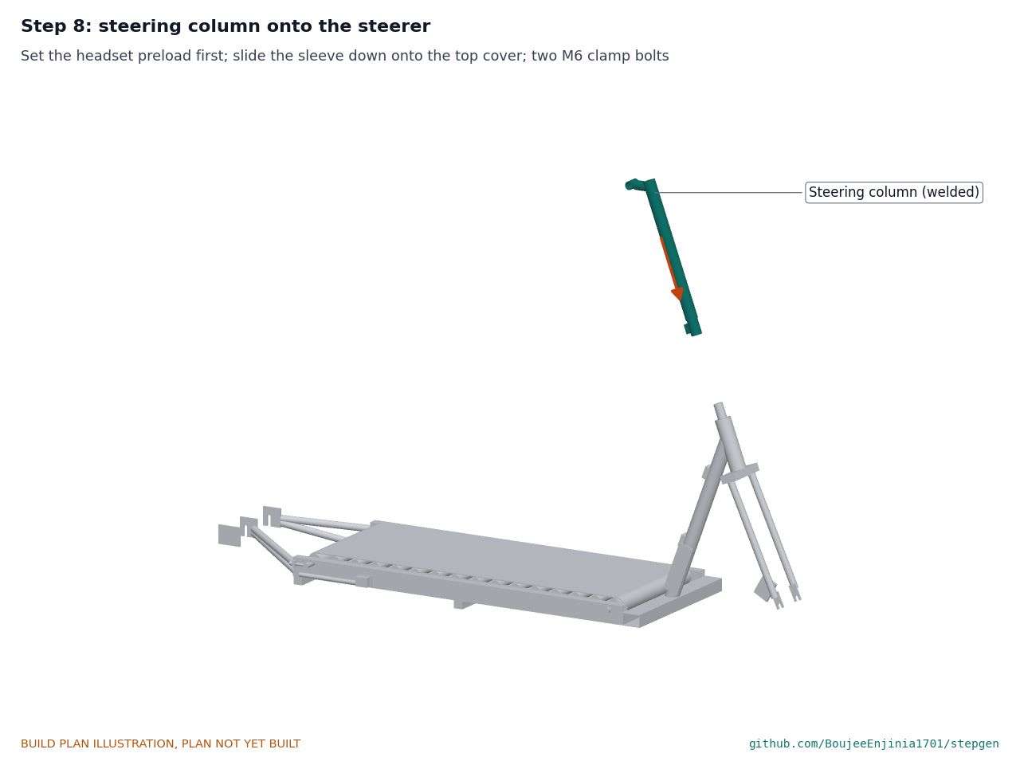
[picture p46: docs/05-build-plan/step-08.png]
Step 8


Set the headset preload first with a temporary stem or a steerer clamp collar, then remove it. Slide the column's sleeve down onto the top cover, line the bar clamp up square to the fork, and tighten the two M6 clamp bolts. Check the steering turns freely with no play.

### Step 9: handlebar, grips, levers and controls

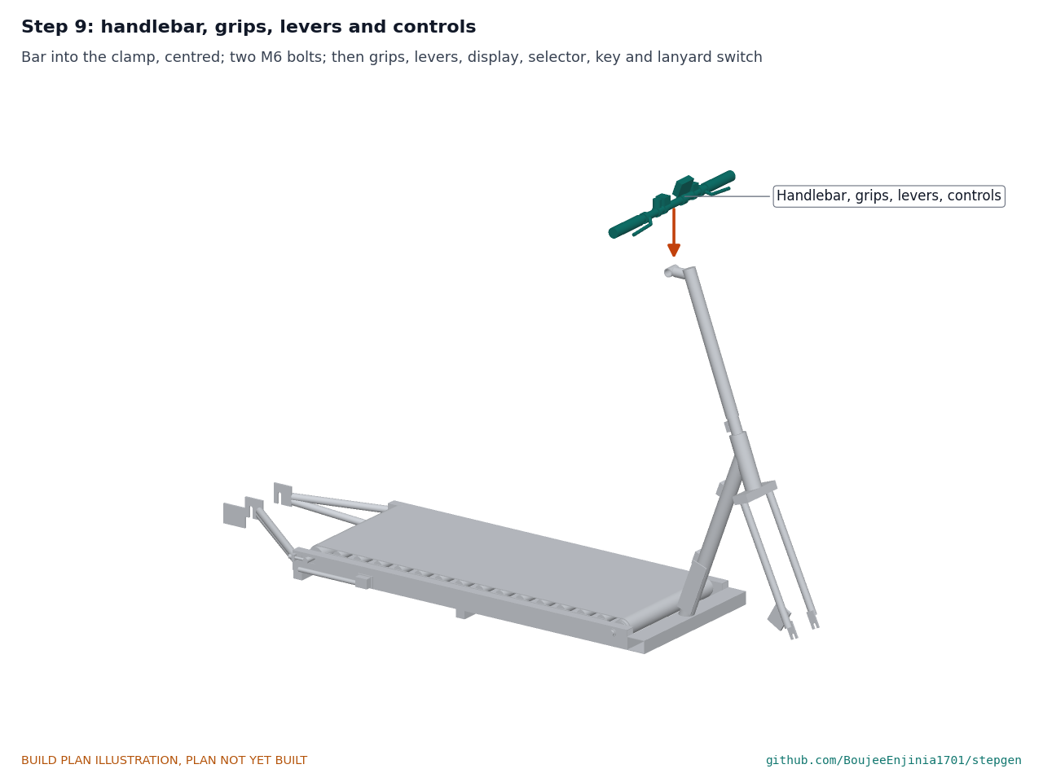
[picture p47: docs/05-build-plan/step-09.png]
Step 9


Bar into the clamp, centred, two M6 bolts. Then the grips, the brake levers inboard of them, the display on the right of the clamp, the selector and key switch on the left, and the lanyard switch beside the display.

### Step 10: front wheel, rotor and caliper

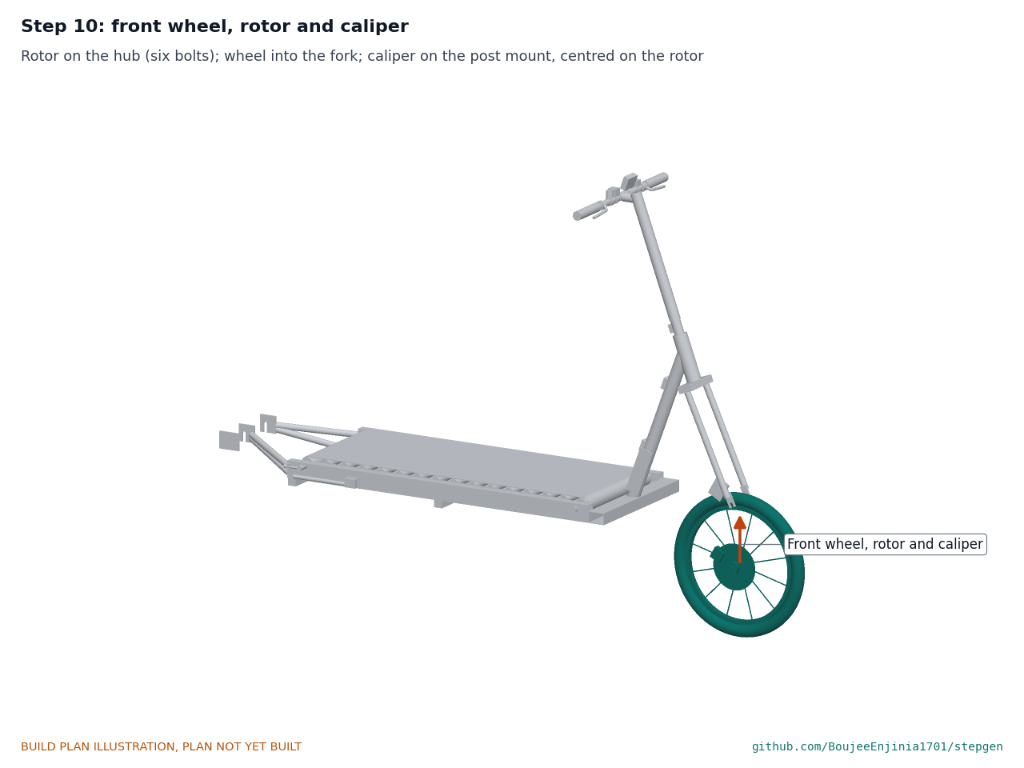
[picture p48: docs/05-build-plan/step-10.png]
Step 10


Bolt the rotor to the hub (six bolts, threadlocker). Fit the wheel into the fork. Bolt the caliper to the post mount, centred on the rotor; connect the left lever's cable.

### Step 11: rear wheel with hub motor and torque arms

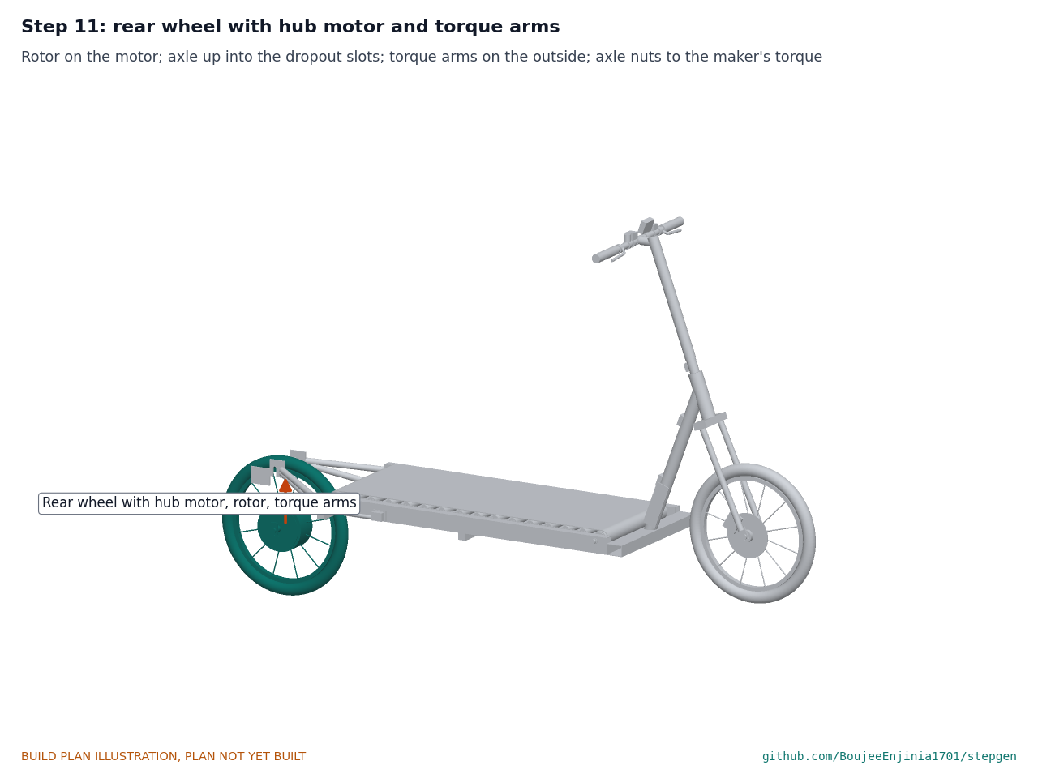
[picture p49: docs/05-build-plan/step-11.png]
Step 11


Bolt the rotor to the motor. Lift the wheel up into the dropout slots, motor cable on the left. Fit the torque arms on the outside of the dropouts with their M6 bolts, then the axle nuts to the motor maker's torque. **Hold point:** the torque arms bear on the axle flats on both sides.

### Step 12: rear caliper

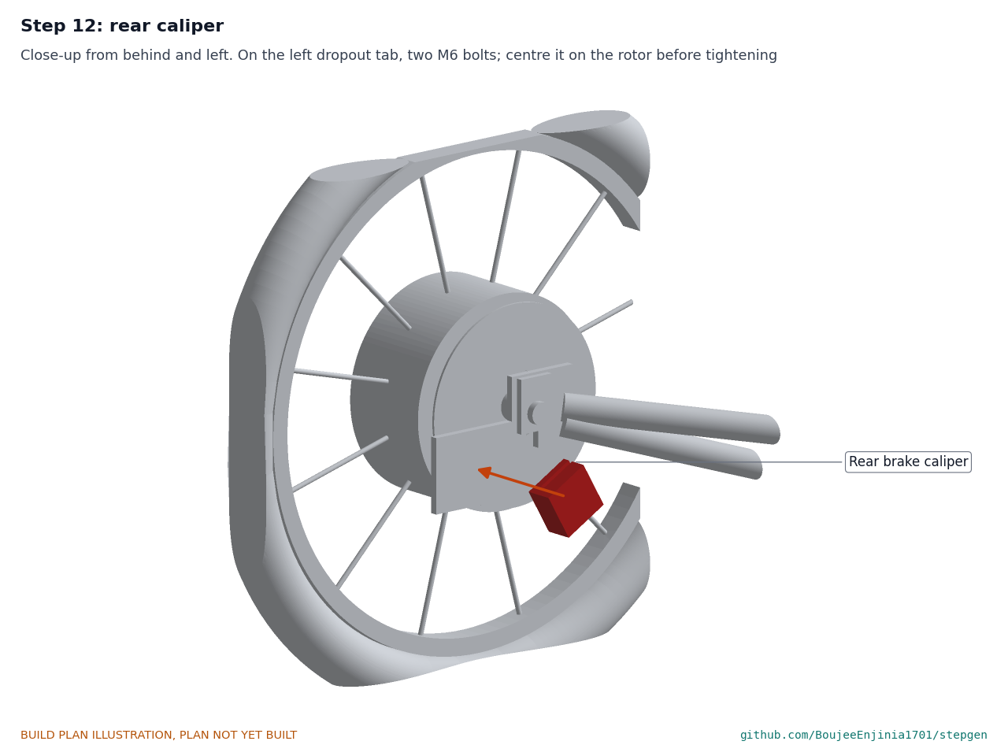
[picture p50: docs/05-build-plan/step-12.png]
Step 12


Seen from behind and to the left, close up. Hold the caliper on the left dropout tab, centred on the rotor; mark and drill the two 6.5 mm holes, then bolt it on and connect the right lever's cable.

### Step 13: controller and wiring harness

Step 13

Controller on its plate, four bolts. Run the harness as in Figure 29: from the controller down to the nose beam, through the left rail between its grommets to the rear, and along the left upper stay to the motor; and up the left side of the down tube and the column to the handlebar, with a loose loop at the head tube so the bar turns 45 degrees each way. Fuse out.

Figure 29. Block-level wiring

*Figure 29. Block-level wiring with wire sizes. No circuit board is laid out; bought modules are wired together.*

Wire it like this, with crimped terminals or ferrules on every end:

1. Cradle receptacle to the fuse holder and on to the controller's battery input: 2.5 mm² (14 AWG).
2. Fuse output to the logic board's buck converter input: 0.5 mm² (20 AWG).
3. Receptacle INTERLOCK and SGND pins through the key switch and the 10 kΩ ±1 % coding resistor in series: 0.25 mm² (24 AWG).
4. Receptacle CAN pins to the logic board's CAN transceiver: 0.25 mm², twisted pair.
5. Brake lever switches and the lanyard switch to the controller's brake-cut input, and also to two logic board inputs: 0.25 mm².
6. Belt speed sensor, display and level selector to the logic board: 0.25 mm².
7. Logic board's speed command output to the controller's speed input: 0.25 mm².
8. Motor cable to the controller, through its keyed connector.

### Step 14: receiver cradle onto the down tube

Step 14

Two M6 bolts into the tabs. Plug the receptacle's lead into the harness.

### Step 15: roller covers and heel guard

Step 15

Cover tabs on the rails' inside walls, one M5 screw each. Heel guard flange on the rear cross member, two M6 screws.

### Step 16: fender and toe guard

Step 16

Fender stays to the dropouts, front tab riveted to the heel guard with two 4 mm rivets. Toe guard flanges on the nose beam, four M6 screws.

### Step 17: side boards

Step 17

Each board on its four spacers, M6 x 25 mm screws into the rail tops.

### Step 18: SwapCell pack

Step 18

Only after safety stops S1 to S6. Key off. Slide the pack down the cradle onto its receptacle and close the lever over its handle end until it snaps over centre.

## 5. First checks

These are the checks a TRL 4 test report would record; this plan only lists them. Requirement numbers are those of SGN-REQ-001.

*Table 2. First checks.*

| Check | Requirement | How | Pass when |
| --- | --- | --- | --- |
| Belt direction and drag | R1, R7 | Pull the belt by hand both ways; spring balance at 5 km/h equivalent push with the drag screw off and fully in | Runs rearward only; 22 to 30 N push with 80 kg on the deck (measured at TRL 4) |
| Belt tension and tracking | R1 | Turn the belt 20 turns by hand | Stays within 5 mm of centre; no slip on the rear roller when braced |
| Step-off height and side boards | R8 | Tape measure; feeler | Belt top 240 mm or less above the floor; 2 mm or more under each board |
| Steering | R10 | Turn the bar to 45 degrees each way | Nothing touches; harness loop not tight |
| Brakes | R7 | Squeeze each lever with the wheels lifted | Each wheel locks; the motor cut-off switch opens on each lever |
| Wake and sleep | R11 | Pack in, key on, then key off (fuse in, wheels lifted) | Pack wakes on key on; output off within 1 ms of key off |
| Motor only while walking | R2 | Wheels lifted; turn the belt by hand, stop it; pull a brake lever; pull the lanyard | Motor runs only while the belt turns above 1.5 km/h; stops within 0.5 s of each stop |
| Speed limit | R3 | Wheels lifted, belt turned fast by hand | Assist cut at 25 km/h (15 km/h in beginner mode) on the display |
| Pack retention | R13 | Lever force with a spring balance; pull on the pack | Lever closes with 50 N or less; the pack does not move |
| Guards | R9 | Reach gauge to ISO 13857 at both belt ends and the rear tire | No finger or toe reaches a nip |
| Size and mass | R10 | Tape measure; scale | 2.4 m or less long, 0.65 m or less wide, 40 kg or less with the pack |

## 6. Safety stops

Stop at each point. Carry on only when everything listed is true.

- **S1. Before the frame is welded.** Welding screen, gloves, mask and ventilation in place; galvanising and paint ground off; fire extinguisher at hand.
- **S2. Before anyone stands on the belt.** All frame welds inspected with no cracks; every axle bolt and tension bolt tight with its lock nut; side boards, heel guard, toe guard and covers fitted; both brakes work; the kickstand holds the vehicle upright.
- **S3. Before the pack comes into the workshop.** Pack charged only in a SwapCell dock, never on the vehicle; a non-combustible place to stand the vehicle; a fire extinguisher for electrical fires within reach.
- **S4. Before the fuse goes in.** With the pack out, the harness checked end to end; the receptacle's power pins read open to the frame; the key switch opens the INTERLOCK loop; every connector seated.
- **S5. Before the motor is powered.** Rear wheel lifted clear of the floor on a stand; lanyard clipped to the tester; both brake levers cut the motor; fingers and clothing clear of the belt ends and the rear tire.
- **S6. Before the pack goes in.** S4 and S5 done; the cradle lever snaps over centre; key off.
- **S7. Before the first ride (TRL 4, outside this plan).** All first checks passed; helmet and a closed, flat, private area; the legal category confirmed with the Dutch vehicle authority (RDW) before any road use (first country decided by Amish, 2026-10-02).

## 7. Tools, skills and workspace

**Tools.** Bandsaw or hacksaw and a metal-cutting chop saw; bench drill with a vice; drills 3 to 17 mm and a step drill; M3, M6 and M8 taps; rivet nut tool for M3, M5 and M6; angle grinder with cutting and flap discs; files including a half round for fish-mouths; MIG or stick welder for 2 to 6 mm mild steel; a flat welding table with clamps and a simple jig for the head tube angle; sheet metal folder or two lengths of angle in a vice for 2 mm aluminium up to 440 mm wide; a 80 mm bar for rolling the covers; jigsaw for HDPE; headset press (or a threaded rod and washers) and a crown race setter; bearing press or a vice with sockets for the one-way bearing; spoke and cone spanners as needed; torque wrench 5 to 40 N·m; multimeter; spring balance to 100 N; tape measure, square, protractor, calipers.

**Skills.** Basic metalwork and steel welding (a local welder can weld the frame from the cut pieces); bicycle mechanics (headset, disc brakes, wheel fitting); crimping and simple wiring. Every circuit is below 60 V DC; no mains wiring is part of this build.

**Workspace.** A welding area apart from the assembly bench; a bench at least 2.5 m long or two trestles for the frame; a stand that holds the rear wheel off the floor; the safe pack area of S3.

**Personal protective equipment.** Welding helmet, gloves and jacket; safety glasses for cutting, drilling and grinding; hearing protection when grinding and sawing; cut-resistant gloves for sheet; no gloves near a turning drill.

## 8. Where the numbers come from

- Model and constructability checks: `cad/src/model.py` (`python cad/src/model.py --check`); STEP and STL exports in `cad/step/` and `cad/stl/`.
- Pictures: `cad/src/build_plan_media.py`, using `.kit/build_views.py`; written to `docs/05-build-plan/` and `cad/drawings/SGN-DWG-101` to `SGN-DWG-114`.
- General arrangement: `cad/drawings/SGN-DWG-001.pdf`, Rev P3.
- Calculations: `docs/04-calcs/01-sizing.md` (SGN-CAL-001 v0.3) and `docs/04-calcs/sizing.py`.
- Bill of materials: `bom/bom.csv` and `bom/bom-notes.md`.
- Decisions: `docs/decisions/0003-design-for-construction.md` (SGN-DDR-003), with SGN-DDR-001 and SGN-DDR-002; the register `docs/06-design-decisions.md` (SGN-DEC-001).
- Requirements: `docs/03-requirements.md` (SGN-REQ-001 v0.6).

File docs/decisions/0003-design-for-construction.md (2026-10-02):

---
doc_id: SGN-DDR-003
title: StepGen design for construction
project: StepGen
doc_type: Design decision record
version: "0.2"
status: Draft
date: '2026-10-02'
author: Amish Chadha
license: CERN-OHL-S-2.0
revisions:
- version: "0.1"
  date: '2026-10-01'
  author: Amish Chadha
  change: Changes that make the concept physically buildable, with the reason for each; made under Amish's 2026-09-30 instruction and open for his review
- version: "0.2"
  date: '2026-10-02'
  author: Amish Chadha
  change: 'Accepted by Amish on 2026-10-02 as made; record stays Draft'
---

# 0003: Design for construction

- **Date:** 2026-10-01
- **Status:** accepted. The changes in Tables 1 and 2 were made under Amish's 2026-09-30 instruction to make the design physically buildable. Amish, 2026-10-02: "i approve your recommendations for all 555 open decisions." This accepts P1 to P17 and their knock-on changes as made, recorded in the design decisions register (SGN-DEC-001). Nothing here changes what StepGen does, its pitch or its safety case. The record stays Draft.

## Context

On 2026-09-30 Amish approved the build plan format for the portfolio and asked for it to be extended to every repo, with outstanding decisions kept in a separate design decisions register. For the drawings he wrote: "If you are realising that the design cannot be built as per concept - fix the design assumptions to match and be physically feasible as you draw the illustrations."

The TRL 3 model of SGN-DDR-002 was a massing model: correct sizes and interfaces, but many parts were simplified shapes that overlapped, floated or had no fixing. A build123d check of that model found 23 pairs of components that overlapped (the upper rear stays ran through the rear roller and belt; the brake rotors sat outside the dropouts; the fork crown overlapped the down tube) and many parts with nothing holding them (cross members, roller bed carriers, side boards, guards, controller, kickstand).

The changes below keep what StepGen does: the same 20 in wheels, wheelbase (1855 mm), steering geometry (70 degrees, 30 mm offset, 58 mm trail), belt (1.05 m roller pitch, 400 mm wide, top 240 mm above the ground), roller bed, motor, brakes, pack position and SwapCell interface v0.3 receiver, bar height and controls. Every change is in `cad/src/model.py`, which is now built from 29 components and runs 72 constructability checks (`python cad/src/model.py --check`): parts that must touch do touch, parts that must stay apart are apart by at least the stated gap, no two components overlap, and the front wheel and fork clear the frame, toe guard, controller, cradle and pack at 45 degrees of steering lock each way. All 72 pass.

## Decision

*Table 1. Changes made to the model, the BOM and the calculations.*

| # | Problem in the concept | Change made | Why this way |
| --- | --- | --- | --- |
| P1 | The upper rear stays ran from the rails 450 mm ahead of the axle through the rear roller and the belt. | Two stays each side, 22 x 1.6 mm: an upper stay from a 3 mm end cap on the rail's rear end, and a lower stay from the rear face of the rear cross member, both to the dropout. | The stays now stay behind the deck. The two stays per side form a triangle in the vertical plane, so the cantilevered rear end is stiff. |
| P2 | The brake rotors sat outside the dropouts and fork legs (rear 95 mm, front 70 mm from the centre line), where a disc hub cannot carry them; the calipers had no mount. | Rotors on the hubs' 6-bolt mounts inside the dropouts: rear 52 mm and front 34.5 mm left of centre. Rear caliper on a tab on the left dropout plate; front caliper on the fork's post mount. | Standard disc positions for a 135 mm motor hub and a 100 mm front hub. |
| P3 | The dropouts were blocks with no slot; the hub motor had no torque arms modelled. | 6 mm dropout plates 135 mm apart inside, slots open downward; a torque arm on the outside of each dropout. | A hub motor in steel dropouts needs torque arms; the slot lets the wheel drop out. |
| P4 | The fork legs overlapped the front hub, and the fork crown and steerer had no headset. The 44 x 3 mm head tube could not take a headset. | Fork legs either side of a 100 mm hub; a bought steel head tube 50 x 3 mm machined for a ZS44 headset; headset modelled. The fork is a 26 in size rigid fork (axle to crown about 410 mm) carrying the 20 in wheel, because the head tube sits 640 mm up. | Keeps the decided head angle, offset, trail and bar height. A 20 in fork is about 80 mm too short for this head tube. |
| P5 | The down tube met the head tube at its bottom end and overlapped the fork crown; at even 35 degrees of steering the crown would strike it. | The down tube's axis meets the steering axis 100 mm above the head tube's bottom, and it is mitred to the head tube's side. | The fork now turns 45 degrees each way with 10 mm to spare (checked); the crown reaches the down tube between 50 and 60 degrees. |
| P6 | Two nose tubes and a block crossed under the front of the deck; the down tube stood on the block. | A 60 x 40 x 2 mm nose beam across the front ends of the rails; the down tube stands on its top. | One straight member, square cuts, flat faces for the down tube, the toe guard and the harness. |
| P7 | The three cross members cut 15 mm into each rail and floated. | Two 25 x 25 x 2 mm cross members welded under the rails (rear and middle); the nose beam ties the front. Ground clearance 145 mm (was 148 mm). | A cross member under the rails is welded on two full faces and clears the belt's return run by 14 mm. |
| P8 | The end rollers' axles passed through the rails with no fixing; the tensioner and the anti-reverse clutch housing were shapes outside the right rail with no mount; the speed sensor's magnet ring sat outside the rail on an axle that does not turn. | Fixed 17 mm axles: the front one held by an M10 bolt through each rail (with a crush tube welded inside the rail); the rear one in 45 mm slots, pulled back by two M8 tension bolts through welded lugs. The anti-reverse clutch is a one-way bearing of the same size as the roller's own bearing (CSK17 class for a 6203), pressed into the rear roller. The belt drag is a felt-tipped M8 thumb screw through the right rail onto the rear roller's end. The magnet ring is glued to the front roller's left end face, read by a Hall sensor on a small bracket inside the left rail. | Treadmill rollers have fixed axles and internal bearings; this keeps a salvaged roller usable and puts nothing outboard. The bearing takes about 6 N m against about 56 N m rated. Lean clearance rises from 30 to 32.6 degrees, now set by the kickstand. |
| P9 | The belt overlapped the rollers by 3 mm (the roller centres were set from the belt top without the belt's thickness). | Roller centres 3 mm lower, so the belt wraps the rollers and its top is still 240 mm above the ground. | Belt top and step-off height unchanged. |
| P10 | The idler rollers ran into their carriers; the carriers floated inside the rails. | Two 50 x 3 mm aluminium carrier bars bolted flat to the rails' inside walls with M6 rivet nuts; the idlers' spring axles snap into holes in the bars. | The rollers' standard spring axles need a flat bar with holes; rivet nuts work in a 2 mm wall. |
| P11 | The side boards floated 10 mm above the rails and touched the belt edge. | 6 mm HDPE boards on four 13 mm spacers per side, bolted into rivet nuts in the rail tops; 5 mm over the belt edge with 3 mm clearance above it (now 9 mm proud of the belt). | The boards still cover the belt edges and leave the sides open (R8). |
| P12 | The heel guard, roller covers and toe guard floated; the fender ran into the heel guard. | Heel guard with a bottom flange screwed to the rear cross member; roller covers with end tabs screwed to the rails' inside walls; toe guard leaning back 20 degrees with flanges on the nose beam (notched round the down tube); a bought 20 in fender riveted to the heel guard and stayed to the dropouts. | Every guard has a flat face to fix to. The front cover now covers the front roller's lower front quarter, where the in-running nip is. |
| P13 | The receiver cradle was a 16 mm solid block on the down tube; its lever post stood where the pack's handle is. | A folded 3 mm channel on two welded tabs (two M6 bolts), a 12 mm end stop plate with the floating receptacle, and an over-centre lever on a pin between ears on the channel walls, its pad pressing the pack's handle end. The pack sits 0.54 of the way up the down tube (was 0.55). | Keeps class V1 preload (330 N) and the 1 mm guide clearance, and puts the lever beside, not on, the handle. |
| P14 | The controller sat under the down tube, in the front tire's path when steering, with no fixing. | On a welded plate on the left side of the down tube, low down. | Checked clear of the front wheel at 45 degrees of lock. |
| P15 | The steering column had no joint to the fork steerer; the stem and bar had no clamp; the grip bends and controls overlapped each other. | A welded column: a slotted 33.7 x 2.3 mm sleeve that clamps the 28.6 mm steerer above the headset with two M6 bolts, the 38 x 2 mm column, a 30 x 2 mm stem and a slotted 26.9 x 2.3 mm bar clamp. A straight 580 mm bar (was 612 mm over swept grips); display, level selector, key switch, lanyard switch and brake levers each on their own bar clamp, apart. The display now faces the rider. | Stock tube sizes slip-fit each other, so it needs no lathe. Width falls from 0.61 to 0.58 m. |
| P16 | The kickstand overlapped the left rail with no mount; the harness ran through the frame and guards. | A bought side kickstand on a welded plate on the left rail. The harness runs inside the left rail between two grommets, along the nose beam, up the left side of the down tube and up the column. | Both now have a place to sit; the harness is out of reach of the belt and wheels. |
| P17 | The rear fender (added in P12) reaches 30 mm behind the rear tire. | Overall length 2.38 m (2.35 m over the tires). | Still inside R10's 2.4 m. |

*Table 2. Knock-on changes.*

| Item | Change | Reason |
| --- | --- | --- |
| Mass | Frame 12.7 kg (was 12.5 kg); vehicle 35.1 kg without the pack, 37.9 kg with it; R10 margin 2.1 kg, unchanged at the first decimal (SGN-CAL-001 v0.3). | Nose beam, end caps, plates and the heavier head tube against two cross members and lighter stays. |
| Cost | BOM lines 1, 2, 3, 4, 5, 7, 8, 9, 10, 12, 13, 14, 15 and 16 restated and repriced. The donor bike's fork no longer fits, so the reference build buys the fork and headset (about USD 40). Value-engineering target USD 650; estimated cost of the constructable design USD 610 on the reference build (USD 40 under the target, was USD 546); all-new fallback USD 750 (was USD 721). | Parts added for construction and the fork change of P4. |
| Geometry | Length 2.38 m with the fender, width 0.58 m, height 1.29 m, ground clearance 145 mm, lean clearance 32.6 degrees. Wheelbase, trail, belt and bar height unchanged. | P7, P8, P15, P17. |
| Drawing | SGN-DWG-001 Rev P3; making sketches SGN-DWG-101 to 114 added. | Follows the model. |
| Documents | SGN-CAL-001 v0.3, SGN-PRC-001 v0.6, SGN-REQ-001 v0.6, `bom/bom-notes.md`. No requirement changed status. R12 is reported against the value-engineering target. | Follows the model. |

*Table 3. Proposed, awaiting Amish.* None. No change in this record alters what the vehicle does, its pitch or its safety case. Items to confirm when parts are bought are listed in the design decisions register (SGN-DEC-001).

## Consequences

- `design_state: constructable` in `project.yaml`. The build plan SGN-BLD-001 shows every component and step in pictures generated from the model (`cad/src/build_plan_media.py`).
- Requirement status is unchanged: none not met; R1, R6 and R10 at risk; R9 and R13 not verifiable at TRL 3; the rest met on paper (SGN-CAL-001 v0.3).
- The photoreal renders (`media/render-*.png`), `media/card.png`, `media/social-preview.png` and the appearance model `cad/src/product_model.py` still show the concept bracket shapes (nose tubes, grip bends, outboard clutch housing, solid cradle). They need updating on Amish's Mac, where Blender is.
- The salvage reference build now buys its fork and headset; the donor bike still supplies the front wheel and brakes.

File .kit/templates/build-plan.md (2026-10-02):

---
doc_id: PRJ-BLD-001
title: Project prototype build plan
project: Project name
doc_type: Build plan
version: "0.1"
status: Draft
date: YYYY-MM-DD
author: Amish Chadha
license: CERN-OHL-S-2.0
revisions:
  - version: "0.1"
    date: YYYY-MM-DD
    author: Amish Chadha
    change: First build plan; design made constructable
---

# Project prototype build plan

**Plan, not yet built.** How to build the first proof-of-concept prototype, component by component. Building and testing to it is TRL 4 work. Decisions still to be made are kept in the design decisions register (`docs/06-design-decisions.md`), not here.

## 1. What you are building

Every component, pulled apart and numbered in build order

One short paragraph: what the prototype is, how many components, which are made and which are bought, and the main ways they are made.

## 2. What changed to make it buildable

| Component | The concept had | The buildable design has | Why |
| --- | --- | --- | --- |

## 3. Making the components

### 3.1 Component name

Making sketch

**What it is and what it is made from.**

**How to make it.**

1. Mark out ...
2. Cut ...

**How it fits the parts next to it.**

Close-up of the joint

**Check before moving on.**

## 4. Putting it together

### Step 1: ...

Step 1

## 5. First checks

| Check | Requirement | How | Pass when |
| --- | --- | --- | --- |

## 6. Safety stops

## 7. Tools, skills and workspace

## 8. Where the numbers come from

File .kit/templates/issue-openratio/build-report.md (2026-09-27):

---
name: Build report
about: Tell us what happened when you built, printed or tested part of this design
title: "Build report: "
labels: build-report
---

This is a research and educational prototype, not a medical device. It is a TRL 3 concept and is not released for fabrication. If you build any part of it, you do so at your own risk. Reports help everyone.

**What you built** (part, sub-assembly or test)

**Materials, tools and settings**

**What worked**

**What did not work, with photos or measurements if you have them**

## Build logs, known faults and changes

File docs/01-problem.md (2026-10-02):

---
doc_id: SGN-PRB-001
title: StepGen problem statement
project: StepGen
doc_type: Problem statement
version: "0.6"
status: Draft
date: '2026-10-02'
author: Amish Chadha
license: CERN-OHL-S-2.0
revisions:
- version: "0.1"
  date: '2026-09-24'
  author: Amish Chadha
  change: Initial scaffold
- version: "0.2"
  date: '2026-09-24'
  author: Amish Chadha
  change: Populate to TRL 2 (users, context, constraints, out of scope, prior work, honest energy framing)
- version: "0.3"
  date: '2026-09-25'
  author: Amish Chadha
  change: Concept changed at Amish's direction from a stationary stepper generator to a walking-treadmill vehicle
- version: "0.4"
  date: '2026-09-25'
  author: Amish Chadha
  change: TRL 3. Record Amish's decisions (SGN-DDR-001) on budget, legal route and co-design partners; SwapCell interface v0.3; numbers checked against SGN-CAL-001
- version: "0.5"
  date: '2026-09-25'
  author: Amish Chadha
  change: Recommendations accepted by Amish (DDR-002)
- version: "0.6"
  date: '2026-10-02'
  author: Amish Chadha
  change: 'Decisions of 2026-10-02: first user group, the Netherlands as first country (RDW), balance as a fixed co-design test, stride check'
---

# StepGen problem statement

Many people who would benefit from an electric bike never use one because riding needs cycling skill, confidence on pedals and a seated posture that does not suit everyone. Walking is the one way of moving that almost everyone already knows. StepGen asks whether a small electric vehicle can be driven by walking: the rider stands upright on a short treadmill belt between the wheels, walks at an ordinary pace, and the vehicle moves forward at e-bike speed.

> **Concept change.** Amish decided on 2026-09-24 that StepGen is a walking-treadmill vehicle in the manner of the Dutch Lopifit walking bike, not a stationary stepper generator. The earlier generator concept, which charged a PowerBox, is dropped entirely. Version 0.2 of this document describes the earlier concept and remains in Git history. On 2026-09-25 Amish accepted the TRL 2 recommendations, including a $650 budget, the route for the legal question and the move to SwapCell interface v0.3 (SGN-DDR-001). The same day he accepted the TRL 3 recommendations, including a salvage reference build that keeps the $650 budget (SGN-DDR-002).

## The problem

Short trips of 2 to 15 km (about 1 to 9 mi) to work, school, a market or a clinic are too long to walk comfortably and too short or too costly for a car or a taxi. E-bikes fill this gap well for people who already cycle. They leave out:

- people who never learned to ride, which is common among adults in many countries and among women in some communities;
- older adults and people with some balance or joint limits who are nervous on a saddle and pedals;
- people whose clothing, such as long skirts or wraps, makes a diamond-frame bike awkward;
- people for whom a seated, pedalling posture is uncomfortable, for example after hip or knee problems, while ordinary walking is fine.

Walking needs no new skill. On a walking vehicle the rider stands, holds a handlebar and walks. The walking motion is a natural control input: walk and the vehicle goes, stop walking and it slows. The rider gets light exercise at a walking effort while covering distance at bicycle speeds.

## Why the belt is a control input, not the engine

A person walking puts only a small horizontal force into the ground, because walking is mostly about supporting and moving body weight, not pushing backward hard. On a free-running belt over a roller bed this is about 22 to 30 N (5 to 7 lbf) at 5 km/h, or roughly 30 to 41 W of mechanical power (estimate, see SGN-CAL-001). This vehicle at 20 km/h on the flat needs about 136 W at the wheel with an 80 kg rider. A purely mechanical belt-to-wheel drive would therefore move at about walking pace and would feel harder than walking, and people who built such drives report that they are slower than simply walking ([SolidSmack, "Walk Don't Ride"](https://www.solidsmack.com/design/evolution-unusual-treadmill-bicycle/)).

StepGen is framed around that fact. The belt tells the vehicle that the rider is walking and how fast; an electric hub motor supplies most of the propulsion; and a shared SwapCell battery pack supplies the energy. This is also how the Lopifit works: its 250 W motor drives the vehicle, and the belt does not recharge the battery ([New Atlas](https://newatlas.com/urban-transport/lopifit-electric-scooter-treadmill-bike-walking/)).

## Users and context

| User | Need | Context |
| --- | --- | --- |
| Adults who do not cycle | Cover 2 to 15 km trips without learning to ride | Towns and peri-urban areas with cycle lanes or quiet roads |
| Older adults and people with mild balance or joint limits | An upright, familiar movement with a handlebar to hold | Short errands, clinic visits; must be able to step off easily |
| Commuters who want light exercise | Arrive without sweating, get some walking in | Flat to rolling urban routes, 5 to 15 km each way |
| Riders who share batteries across portfolio vehicles | One pack that also runs SunSpoke, WaterWalker assist and a PowerBox | Households or groups with a SwapCell dock |
| Local builders and bike mechanics | A frame and parts they can build, fix and adapt | Garage or market-town workshop with a welder |

## Constraints

- Garage-buildable prototype with a budget of $650 USD in `project.yaml` (decided by Amish, 2026-09-25), excluding the SwapCell pack, which is priced once in the SwapCell project. Amish decided on 2026-09-25 (SGN-DDR-002) that the reference build uses a salvaged walking-pad treadmill and a donor 20 in bike, which prices at about $546; an all-new build (about $721) is the fallback (see SGN-CAL-001).
- Uses the shared SwapCell pack (interface v0.3: 13S lithium-ion, about 46.8 V nominal, 39.0 to 54.6 V, about 468 Wh, 2.85 kg), with a 10 kΩ coding resistor in the INTERLOCK loop for wake and a vehicle receiver to latch class V1. StepGen must not change the interface locally; conflicts go back to the SwapCell project.
- Legal in intent: stay inside pedelec-like limits (250 W rated motor, assist cut before 25 km/h, motor only while the rider walks) so the vehicle can be argued to be as safe and as limited as an e-bike. Whether it legally counts as one is an open question (see below).
- Safe for untrained riders: no reachable pinch points, motor cut-off when the rider stops walking, lets go of a lanyard or pulls a brake.
- Rider can put a foot on the ground easily: low deck, open sides.
- Fits a cycle lane, a lift and a hallway: narrow and not much longer than a long bicycle.
- Every circuit stays below 60 V DC.

> **Safety:** StepGen puts a standing person on a moving belt on a moving vehicle at up to 25 km/h, powered by a 468 Wh lithium-ion pack at up to 54.6 V DC. Falls, pinch points at the belt rollers and rear tire, braking with feet on a belt, pack retention and battery fire are the main hazards; SGN-PRC-001 lists the controls. Nothing in this repo clears the design for building or riding.

## Legal status

On current rules StepGen does not clearly fit the e-bike category anywhere, because e-bike definitions assume pedals.

- **EU.** Pedal-assisted cycles with a continuous rated motor power up to 250 W, whose assistance is cut before 25 km/h and only while the rider pedals, are excluded from moped type approval ([Wikipedia summary of EN 15194 and Regulation 168/2013](https://en.wikipedia.org/wiki/Pedelec)). A walking vehicle has no pedals. In the Netherlands, guidance for walking bikes says an electric walking bike may use the pavement only up to 6 km/h and must otherwise use the cycle path or road, and that liability insurance is required for electric versions ([Scouters.nl](https://www.scouters.nl/hulpmiddel-keuze/loopfiets-volwassenen/)). Status in other member states is not established here.
- **US.** Federal law defines a low-speed electric bicycle as a two- or three-wheeled vehicle with fully operable pedals and a motor under 750 W with a top motor-only speed under 20 mph ([15 USC 2085](https://uscode.house.gov/view.xhtml?req=granuleid%3AUSC-prelim-title15-section2085&num=0&edition=prelim)). Most states use three classes: class 1 (assist only while pedalling, to 20 mph), class 2 (throttle, to 20 mph) and class 3 (assist only while pedalling, to 28 mph), and all of them require operable pedals ([Redtail, state guide](https://redtailebikes.com/blogs/journal/electric-bike-laws)).

The design therefore targets the stricter EU limits. Amish decided on 2026-09-25 that a first target country is picked and the vehicle's legal category confirmed there before any road use. Amish decided on 2026-10-02 that the first country is the Netherlands, with the category confirmed with the Dutch vehicle authority (RDW) before any road use. EU pedelec rules cover pedal-assisted cycles, so a pedal-less vehicle may fall outside them, and the RDW check may set a lower speed cap or require type approval.

## Out of scope

- Generating household electricity. The earlier stepper generator concept is dropped; StepGen does not charge a PowerBox. It draws from a SwapCell pack like the other portfolio vehicles.
- Cargo carrying beyond a small bag or basket.
- Speeds above 25 km/h, or motors above 250 W rated.
- Mains-voltage electronics or a built-in charger. Packs charge in a SwapCell dock.
- Off-road use.

## Prior work

- **Lopifit (Netherlands).** An electric walking bike with a treadmill belt between a 28 in front wheel and a 20 in rear wheel, a 250 W motor, a 960 Wh battery of about 5 kg, disc brakes front and rear, a top speed of 25 km/h and a claimed range of 50 to 70 km. It is about 2.22 m long, 0.42 m wide and about 55 kg, with a handlebar height of about 1.2 m, and costs from about €2,999 ([Lopifit](https://www.lopifit.com/what-is-a-lopifit/)). Its handles carry sensors that stop the treadmill with a small hand movement. It proves the concept works and is sold, but its price and mass put it out of reach of the users above.
- **Mechanical treadmill bikes.** Belt-driven bicycles without a motor have been built by hobbyists. The reported result is that they are slower than walking because the belt cannot deliver useful torque at low speed ([SolidSmack](https://www.solidsmack.com/design/evolution-unusual-treadmill-bicycle/)).
- **Stand-up elliptical bikes (ElliptiGO).** Mechanical, upright, with an elliptical stride that does deliver strong propulsion, but this is a running-like exercise machine for fit users, not a walking vehicle ([Wikipedia](https://en.wikipedia.org/wiki/ElliptiGO)). The upright posture also costs more air drag than a crouched cyclist.
- **Kick scooters and e-scooters.** Standing, easy to learn, but e-scooters use a throttle and give no exercise, and small wheels cope poorly with rough surfaces.
- **Portfolio siblings.** SunSpoke (bolt-on e-bike kit) and WaterWalker (walking water carrier with optional assist) share the SwapCell pack and the same 250 W hub motor class.

## User research and co-design

Design with, not for: this design is for people the author may not be part of, so requirements come from the people who will use it.

- [ ] Identify a local partner organization (Helpful Engineering network, NGO, cycling charity, older-adult group or university). By Amish's 2026-09-25 rule, community designs pick co-design partners per area later, so the partner stays open.
- [ ] Run co-design sessions with intended users; record who, where and what was learned
- [ ] Validate trip distance, route, speed, balance, step-off and cost assumptions in the field
- [ ] Revise requirements (REQ) from findings before freezing the design

First-session questions:

- Does walking on a moving vehicle feel safe, and at what speed does it stop feeling safe?
- Can users step on and off, and put a foot down, without help?
- Is two-wheel balance acceptable for non-cyclists, or is a three-wheel version needed? A fixed co-design test (decided by Amish, 2026-10-02): if most non-cyclists cannot ride at walking pace after a short trial, the three-wheel version is designed.
- Where would the vehicle be kept, and can users lift or wheel it into a building?

## Open questions

- Which user group to start with? Decided by Amish on 2026-10-02: non-cycling adults of working age who walk or take transit, with older adults as the second group once balance is understood. The partner is picked later, per area.
- Can a two-wheeled walking vehicle be balanced by people who never learned to cycle, or does the first prototype need three wheels? To be learned in co-design, as a fixed test (decided by Amish, 2026-10-02): keep two wheels for now and make balance a fixed co-design test: if most non-cyclists cannot ride at walking pace after a short trial, the three-wheel version is designed.
- What is the legal category of a pedal-less walking vehicle in the first target country? The route is decided (confirm before any road use), and the country is the Netherlands, with the category confirmed with the RDW (decided by Amish, 2026-10-02).
- Is a 1.0 m belt long enough for the intended users? SGN-CAL-001 shows it fits a 1.75 m rider only up to 5 km/h. To be learned in co-design, where stride length on the belt is one of the checks (decided by Amish, 2026-10-02).

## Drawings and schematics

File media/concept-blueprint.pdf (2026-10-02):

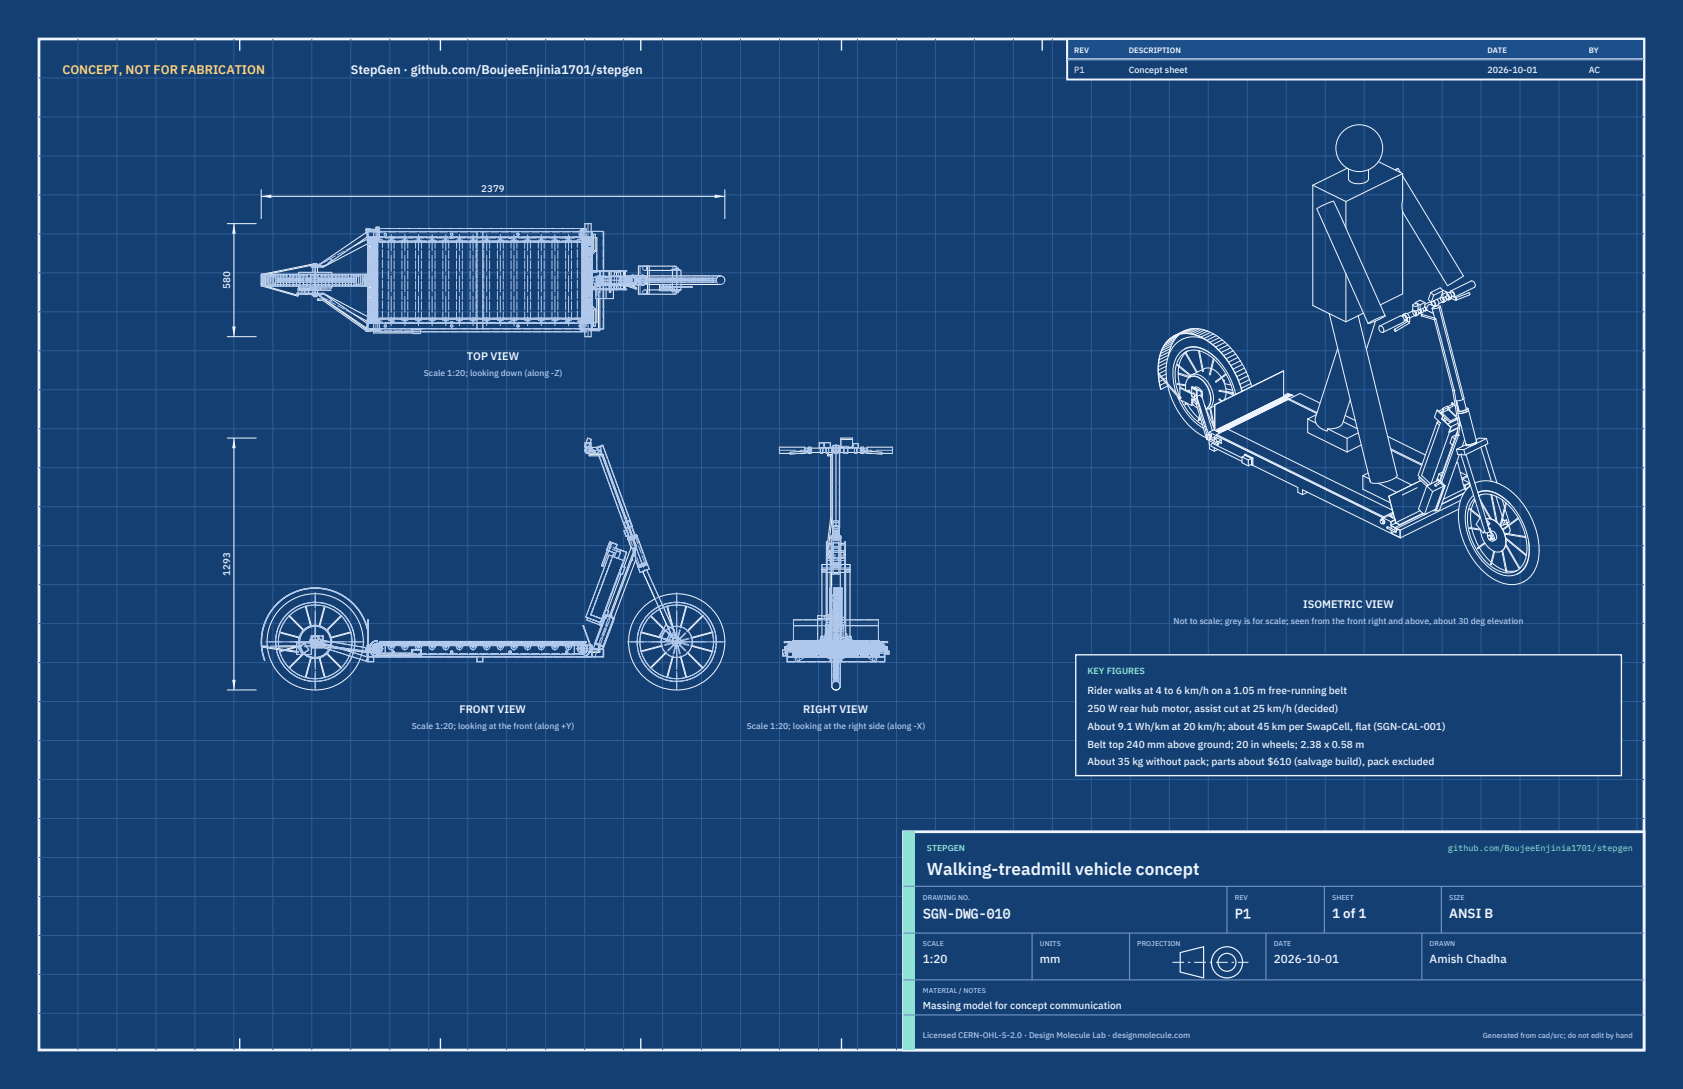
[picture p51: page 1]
CONCEPT, NOT FOR FABRICATION; StepGen · github.com/BoujeeEnjinia1701/stepgen; FRONT VIEW; TOP VIEW; RIGHT VIEW; ISOMETRIC VIEW; REV; DESCRIPTION; DATE; Concept sheet; STEPGEN; github.com/BoujeeEnjinia1701/stepgen; DRAWING NO. SGN-DWG-010; REV P1; SHEET 1 of 1; SIZE ANSI B; SCALE 1:20; UNITS mm; PROJECTION; DRAWN Amish Chadha; Licensed CERN-OHL-S-2.0 · Design Molecule Lab · designmolecule.com; Generated from cad/src; do not edit by hand

Scale 1:20; looking down (along -Z)

Not to scale; grey is for scale; seen from the front right and above, about 30 deg elevation

KEY FIGURES
Rider walks at 4 to 6 km/h on a 1.05 m free-running belt
250 W rear hub motor, assist cut at 25 km/h (decided)
About 9.1 Wh/km at 20 km/h; about 45 km per SwapCell, flat (SGN-CAL-001)
Belt top 240 mm above ground; 20 in wheels; 2.38 x 0.58 m
About 35 kg without pack; parts about $610 (salvage build), pack excluded

Scale 1:20; looking at the front (along +Y)

Scale 1:20; looking at the right side (along -X)

Walking-treadmill vehicle concept

MATERIAL / NOTES
Massing model for concept communication

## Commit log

2026-09-24 Initial scaffold: standard open hardware layout, CERN-OHL-S v2 + MIT licenses
    Claude-Session: https://claude.ai/code/session_01XuhhSU4W6fYhgCfURbrkut
    [bom.csv]
2026-09-25 Adopt portfolio kit v1.3.0: session commands, scale figure, 3D viewer, flow diagrams
    Adds .claude/commands (/populate, /advance-trl3, /rein-in, /refresh-media)
    so every Claude Code session starts from the standard prompts, and extends
    concept media with a 1.75 m scale figure, an interactive glTF viewer and
    system or energy flow diagrams. TRL cap 3 unchanged.
    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
2026-09-25 Kit v1.3.1: renderer fixes from the TremorTrace pilot
    Context scale parts for small objects, cutaway exclusions, and text
    labels in flow diagrams.
    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
2026-09-25 Populate stepgen to a strong TRL 2 with concept media (batch 2)
    Problem, requirements and precis v0.2, massing model and concept media,
    indicative BOM, docs/REVIEW.md with decisions proposed and awaiting Amish.
    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
    [bom.csv]
2026-09-25 Rework StepGen as a walking-treadmill vehicle (concept change by Amish)
    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
    [bom.csv]
2026-09-25 Advance stepgen to TRL 3 (batch 2)
    Decisions approved by Amish 2026-09-25 recorded in DDR-001. TRL 4 is on hold.
    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
    [bom.csv, results.csv, stepgen-assembly.step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]
2026-09-26 Accept all recommendations (DDR-002), switch footer to designmolecule.com, add README write-up with new inspiration point
    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
    [bom.csv, results.csv, stepgen-assembly.step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]
2026-09-27 Product appearance model and photoreal renders
    Adds cad/src/product_model.py (appearance model for renders only, all main
    dimensions from model.py) and Blender renders in media/render-*.png,
    captioned with the project, repository and viewing direction. README leads
    with the product render; trl stays 3.
    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
2026-10-01 Image quality pass: legible exploded views, flow diagrams and drawing sheets
    Kit 1.6.1 image layout: the parts list sits in its own column, number bubbles sit on visible parts and never overlap, small parts get a leader, pictures are cropped to the subject, flow labels keep numbers with their units, and sheet captions and the revision table no longer overprint. Concept images, blueprint and general arrangement sheet regenerated; repo-specific labels moved clear of other text and lines.
2026-10-02 Kit 1.7.0: constructable design, illustrated build plan and design decisions register
    The design is now constructable: every part can be made and fits its neighbours, with each change recorded in a Design for construction decision record (made under Amish's 2026-09-30 instruction; ope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
    FlexHand also credits Dr. Geeti Chadha as a contribut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
    [bom.csv, results.csv, stepgen-assembly.step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]
2026-10-02 Record Amish's approval of the open-decision recommendations
    Amish approved the recommendation on every open decision in the design decisions register ("i approve your recommendations for all 555 open decisions.", 2026-10-02). Each decision is moved to Decisio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
2026-10-03 Carry approved follow-ups into the design and redo photoreal renders
    Amish approved the follow-up actions from the open-decision sign-off ("APPROVED CHANGES, COMPLETE THESE", 2026-10-02), the design-for-construction change tables in ten repos, the last wave's open dec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

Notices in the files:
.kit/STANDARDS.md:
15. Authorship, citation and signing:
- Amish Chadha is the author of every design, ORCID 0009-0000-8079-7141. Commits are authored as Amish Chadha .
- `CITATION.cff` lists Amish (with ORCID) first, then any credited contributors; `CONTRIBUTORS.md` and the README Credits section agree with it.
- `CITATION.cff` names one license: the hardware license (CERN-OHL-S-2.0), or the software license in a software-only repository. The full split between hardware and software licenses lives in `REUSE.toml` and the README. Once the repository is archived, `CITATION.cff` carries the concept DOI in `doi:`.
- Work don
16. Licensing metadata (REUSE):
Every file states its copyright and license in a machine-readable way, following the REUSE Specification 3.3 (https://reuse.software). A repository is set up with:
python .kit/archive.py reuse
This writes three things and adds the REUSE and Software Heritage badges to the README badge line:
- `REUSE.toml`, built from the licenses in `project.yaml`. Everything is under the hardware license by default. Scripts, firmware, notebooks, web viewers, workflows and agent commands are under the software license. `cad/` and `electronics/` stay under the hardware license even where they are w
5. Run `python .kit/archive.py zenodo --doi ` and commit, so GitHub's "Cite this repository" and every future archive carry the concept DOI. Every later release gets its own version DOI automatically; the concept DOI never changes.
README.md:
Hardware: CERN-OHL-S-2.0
